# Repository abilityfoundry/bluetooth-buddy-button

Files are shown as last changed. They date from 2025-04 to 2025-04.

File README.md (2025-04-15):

# 🟢 Buddy Button

**Open-Source Accessibility. One Click at a Time.**

The Buddy Button is an open-source Bluetooth-enabled switch designed for accessibility. Built to be 3D printed and easily assembled, this device enables users with limited mobility to interact with computers, tablets, or phones using a single press.

Created by [**Ability Foundry**](https://github.com/abilityfoundry), this project is part of our mission to build inclusive, impactful, and low-cost assistive technology tools for everyday use.

---

## 📸 3D Renders

Visual previews of the Buddy Button housing and how it fits together:

| Bottom View | Top View | Assembly View |
|---|---|---|
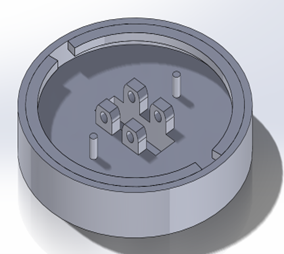
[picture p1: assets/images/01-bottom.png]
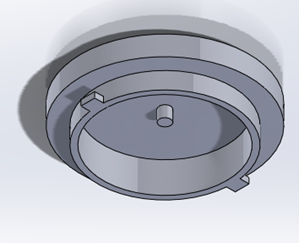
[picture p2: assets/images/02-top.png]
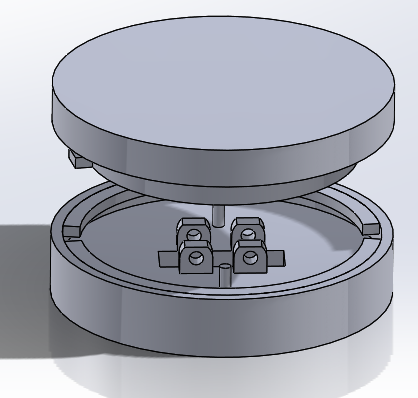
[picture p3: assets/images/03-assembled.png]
|  |  |  |

- **Bottom View**: Shows the internal mounting features for components.
- **Top View**: Displays the enclosure’s inner surface and guiding features.
- **Assembly View**: Illustrates how the top and bottom parts align during assembly.

---

## 🎯 What It Does

- 🖱️ Sends **wireless Bluetooth HID signals** (like keypresses)  
- 🔋 Runs on a **rechargeable LiPo battery**  
- 🌈 Uses a **NeoPixel RGB LED** for visual status  
- 🧩 Built to be **modular and customizable** (shape, color, sensitivity)  
- 🛠️ Easy to assemble using **3D-printed parts** and off-the-shelf components  

---

## 🧱 What's in This Repo

- `Buddy Button Instructions.md` – Complete build instructions  
- `/assets/buddy_button.ino` – Arduino code  
- `/assets/STLs/` – 3D-printable STL files  
- `/assets/SLDPRTs/` – Editable SolidWorks CAD files  

---

## 🛠️ Requirements

- Adafruit Feather nRF52 Bluefruit LE  
- 150–500mAh LiPo Battery  
- RGB NeoPixel  
- Spring (McMaster #9657K289)  
- Momentary switch  
- Basic soldering + 3D printer  

Full list with prices and links is in the [Hardware Components](https://github.com/abilityfoundry/bluetooth-buddy-button/blob/main/Buddy-Button-Instructions.md) section of the instructions.

---

## 🚀 Get Started

1. Print the button housing from the STL files  
2. Order components (linked in the guide)  
3. Flash the Arduino code to the Feather  
4. Assemble, pair via Bluetooth, and press to interact

---

## 🤝 Contribute

Have ideas for improving the design? Want to help make assistive tech more accessible and affordable? We welcome contributions! Open an issue or submit a pull request.

---

**Ability Foundry**  
> Building technology for a more inclusive future.  
> https://github.com/abilityfoundry

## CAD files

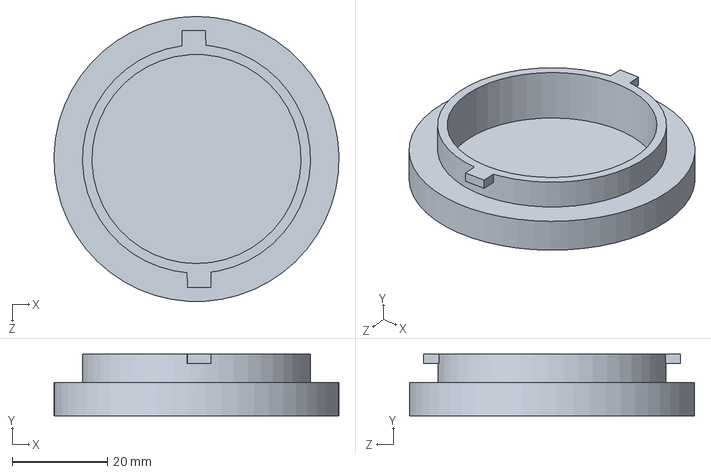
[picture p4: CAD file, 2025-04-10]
assets/SLDPRTs/bb-top.SLDPRT
60.0 x 13.0 x 60.0 mm

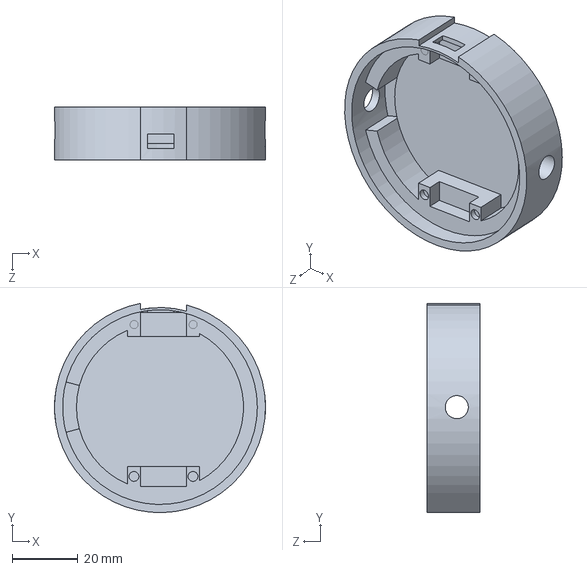
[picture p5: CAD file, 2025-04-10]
assets/SLDPRTs/bb-base.SLDPRT
64.0 x 63.4 x 16.0 mm

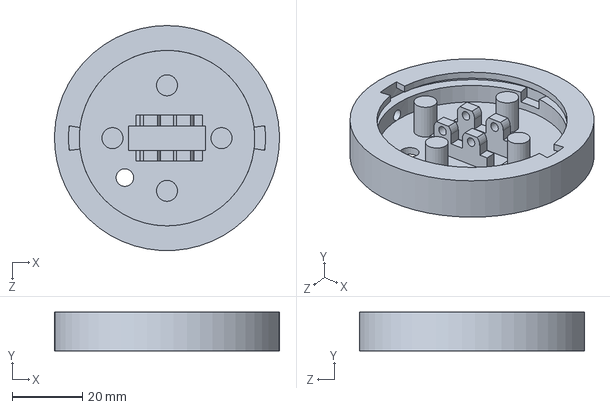
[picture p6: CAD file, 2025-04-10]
assets/SLDPRTs/bb-bottom.SLDPRT
64.0 x 11.0 x 63.9 mm

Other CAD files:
assets/STLs/bb-base.stl
assets/STLs/bb-bottom.stl
assets/STLs/bb-top.stl

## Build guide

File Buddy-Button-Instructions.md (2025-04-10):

# Ability Foundry Bluetooth Buddy Button Project

## Included Files
This repository contains everything you need to build your own Buddy Button:

- `/Buddy Button Instructions.md` — You are reading it now.
- `/assets/buddy_button.ino` — Arduino sketch for controlling the button’s behavior
- `/assets/SLDPRTs/` — SolidWorks files for the top, bottom, and base components (`bb-top.SLDPRT`, `bb-bottom.SLDPRT`, `bb-base.SLDPRT`)
- `/assets/STLs/` — Exported STL versions for easy 3D printing
- `/Parts List.txt` — Links and descriptions for all recommended components

## Table of Contents
- [Overview](#overview)
- [Hardware Components](#hardware-components)
- [Mechanical Design](#mechanical-design)
- [Electronics Setup](#electronics-setup)
- [Code Explanation](#code-explanation)
- [How to Upload the Code](#how-to-upload-the-code)
- [Usage](#usage)
- [Future Improvements](#future-improvements)
- [References](#references)

---

## Overview
The **Buddy Button** is a customizable, accessible Bluetooth-enabled button designed for users with motor disabilities or for use in maker projects. It combines a tactile, 3D-printed enclosure with internal electronics capable of sending **wireless HID signals** (like keypresses) to a phone, tablet, or computer. Key features include:

- A **mechanical spring-loaded design** that gives responsive feedback.
- A **NeoPixel RGB LED** that indicates status (e.g., charging, pairing, low battery).
- **Bluetooth HID support** using the Adafruit Feather nRF52 Bluefruit LE, allowing the button to act like a wireless keyboard or mouse.
- **Rechargeable power** using a small **LiPo battery** (150–500mAh).
- **Modular customization** options such as different button tops, textures, and spring sensitivities.

### Example Use Cases
- Assistive tech for users needing a larger or more responsive external button.
- DIY projects where Bluetooth control is needed via a tactile input.
- Classroom demos for HID/Bluetooth hardware projects.

### Key Parts Used
- [**Adafruit Feather nRF52 Bluefruit LE**](https://www.adafruit.com/product/3406) — BLE microcontroller with HID support  
- [**LiPo Batteries - 150mAh**](http://www.adafruit.com/product/1317) and [500mAh**](https://www.adafruit.com/product/1578) — rechargeable power sources  
- [**RGB Smart LED (NeoPixel)**](https://www.adafruit.com/product/1260) — status indication  
- [**Spring (McMaster #9657K289)**](https://www.mcmaster.com/9657k289) — provides resistance and travel in button press  
- [**Feather Header Kit**](http://www.adafruit.com/product/2886) and [**Stacking Headers**](http://www.adafruit.com/product/2830) — to mount components cleanly inside the case

This modular design allows for experimentation and refinement across mechanical and electronic domains. The current iteration is Version 5, which uses a twist-to-lock mechanism and a fully embedded rechargeable system .

---

## Hardware Components
| Item | Description | Qty | Cost |
|---|---|-----|---|
| [Adafruit Feather nRF52 Bluefruit LE](https://www.adafruit.com/product/3406) | BLE HID microcontroller | 1 | $24.95 |
| [Feather Header Kit](http://www.adafruit.com/product/2886) | 12-pin and 16-pin male headers | 1 | $0.95 |
| [Feather Stacking Headers](http://www.adafruit.com/product/2830) | Female headers for stacking | 1 | $1.25 |
| [LiPo Battery - 3.7v 150mAh](http://www.adafruit.com/product/1317) | Rechargeable battery | 1 | $5.95 |
| [LiPo Battery - 3.7v 500mAh](https://www.adafruit.com/product/1578) | Alternative for longer runtime | 1 | $7.95 |
| [RGB Smart LED](https://www.adafruit.com/product/1260) | Status indicator light | 1 | $6.50 |
| [Spring (McMaster #9657K289)](https://www.mcmaster.com/9657k289) | Tactile feedback mechanism | 1 | $1.00 |
| 3D Printed Housing | Top and bottom shell | 1 | ~$2.00 (varies) |

Total estimated cost per unit: **$48.55**

---

## Mechanical Design

The mechanical design consists of:

- **Top Half**: Moves vertically when pressed. Contains a groove and locking tabs to allow travel and retention.
- **Bottom Half**: Holds the electronics and spring. Designed with cutouts for lock tabs and spring supports.

STL files for 3D printing are located in `/assets/STLs`. Original SolidWorks files are in `/assets/SLDPRTs`.

### Design Iterations
- **Version 3**: Reduced wall thickness to 1.5mm, improved space economy.
- **Version 4**: Added a twist-lock mechanism; adjusted tolerances for tighter fits.
- **Version 5**: Refined locking system, added a track-based twist-to-lock system with 2mm travel.

Wall thickness and spring support dimensions were iteratively refined for structural integrity without excess bulk. Design feedback was gathered by testing spring rigidity and assembly friction (see design notes in `/Parts List.txt` and source files).

---

## Electronics Setup

1. **Microcontroller**: Adafruit Feather nRF52
2. **Power**: LiPo battery connected to JST port (built-in charging circuit used)
3. **LED**: NeoPixel on pin D6, powered by 3.3V and grounded
4. **Battery Monitoring**: Analog pin A7 reads battery voltage through a voltage divider
5. **Button Input**: Momentary switch connects to a digital input pin

---

## Code Explanation

**File**: `/assets/buddy_button.ino`

### Battery Voltage Reading
```cpp
#define VBAT_PIN          (A7)
#define VBAT_MV_PER_LSB   (0.73242188F)
#define VBAT_DIVIDER      (0.71275837F)
#define VBAT_DIVIDER_COMP (1.403F)
```
These constants allow the analog input to read and compute the real battery voltage.

### BLE HID Setup
```cpp
BLEUart bleuart;
BLEHidAdafruit blehid;
BLEDis bledis;
```
These initialize the HID services for the device to act like a Bluetooth keyboard/mouse.

### LED Setup
```cpp
Adafruit_NeoPixel strip = Adafruit_NeoPixel(60, PIN, NEO_GRB + NEO_KHZ800);
```
This sets up the NeoPixel strip (or single LED). Adjust number as needed.

### Loop Logic
In `loop()`, it checks BLE connections, reads the button state, updates LED colors, and triggers HID actions.

---

## How to Upload the Code

1. Install the **Arduino IDE**.
2. Add **Adafruit nRF52** boards via the Board Manager.
3. Install required libraries:
   - Adafruit Bluefruit nRF52
   - Adafruit NeoPixel
4. Connect the Feather to USB and select it under **Tools > Port**.
5. Open `/assets/buddy_button.ino` and click **Upload**.

---

## Usage

1. **Power On**: Plug in a LiPo battery or USB.
2. **Bluetooth Pairing**: Look for `Bluefruit52` on your phone/tablet/computer and pair.
3. **HID Activation**: Press the button to send key presses or other actions (customize in code).
4. **LED Status**: NeoPixel changes color based on charge/pairing/state.

---

## Future Improvements

- Slimmer housing with even smaller battery
- Software configuration to change actions
- Stronger or softer springs depending on user feedback
- Optional wired version for simpler setups
- Improved app integration for iOS/Android

---

## References

- [Adafruit Feather nRF52 Guide](https://learn.adafruit.com/bluefruit-nrf52-feather-learning-guide/downloads)
- [NeoPixel LED Downloads](https://learn.adafruit.com/flora-rgb-smart-pixels/downloads)

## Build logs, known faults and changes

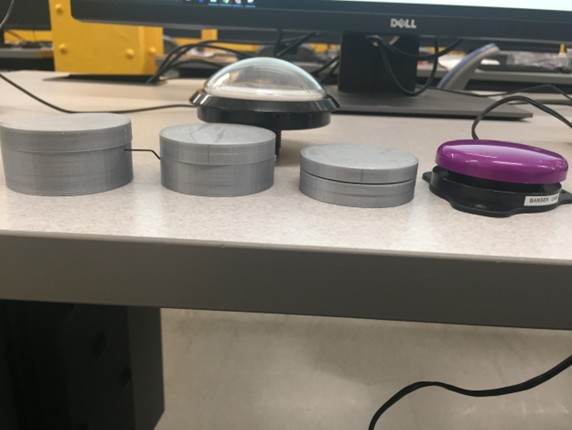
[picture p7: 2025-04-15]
assets/images/version-history.jpg

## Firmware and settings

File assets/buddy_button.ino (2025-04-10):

#define VBAT_PIN          (A7)
#define VBAT_MV_PER_LSB   (0.73242188F)   // 3.0V ADC range and 12-bit ADC resolution = 3000mV/4096
#define VBAT_DIVIDER      (0.71275837F)   // 2M + 0.806M voltage divider on VBAT = (2M / (0.806M + 2M))
#define VBAT_DIVIDER_COMP (1.403F)        // Compensation factor for the VBAT divider

// HID bluetooth
#include <bluefruit.h>

#include <Adafruit_NeoPixel.h>
#ifdef __AVR__
  #include <avr/power.h>
#endif
// Function prototypes for packetparser.cpp
uint8_t readPacket (BLEUart *ble_uart, uint16_t timeout);
float   parsefloat (uint8_t *buffer);
void    printHex   (const uint8_t * data, const uint32_t numBytes);

// Packet buffer
extern uint8_t packetbuffer[];

BLEUart bleuart;
BLEDis bledis;
BLEHidAdafruit blehid;
//Color LED


#define PIN 6

Adafruit_NeoPixel strip = Adafruit_NeoPixel(60, PIN, NEO_GRB + NEO_KHZ800);





bool hasKeyPressed = false;


int readVBAT(void) {
  int raw;

  // Set the analog reference to 3.0V (default = 3.6V)
  analogReference(AR_INTERNAL_3_0);

  // Set the resolution to 12-bit (0..4095)
  analogReadResolution(12); // Can be 8, 10, 12 or 14

  // Let the ADC settle
  delay(1);

  // Get the raw 12-bit, 0..3000mV ADC value
  raw = analogRead(VBAT_PIN);

  // Set the ADC back to the default settings
  analogReference(AR_DEFAULT);
  analogReadResolution(10);

  return raw;
}

uint8_t mvToPercent(float mvolts) {
    uint8_t battery_level;

    if (mvolts >= 3000)
    {
        battery_level = 100;
    }
    else if (mvolts > 2900)
    {
        battery_level = 100 - ((3000 - mvolts) * 58) / 100;
    }
    else if (mvolts > 2740)
    {
        battery_level = 42 - ((2900 - mvolts) * 24) / 160;
    }
    else if (mvolts > 2440)
    {
        battery_level = 18 - ((2740 - mvolts) * 12) / 300;
    }
    else if (mvolts > 2100)
    {
        battery_level = 6 - ((2440 - mvolts) * 6) / 340;
    }
    else
    {
        battery_level = 0;
    }

    return battery_level;
}

void setup() {

  // Get a single ADC sample and throw it away
  readVBAT();

  //HID part

    Bluefruit.begin();
  // Set max power. Accepted values are: -40, -30, -20, -16, -12, -8, -4, 0, 4
  Bluefruit.setTxPower(4);
  Bluefruit.setName("Bluefruit52");


  // Configure and Start Device Information Service
  bledis.setManufacturer("Adafruit Industries");
  bledis.setModel("Bluefruit Feather 52");
  bledis.begin();

  /* Start BLE HID
   * Note: Apple requires BLE device must have min connection interval >= 20m
   * ( The smaller the connection interval the faster we could send data).
   * However for HID and MIDI device, Apple could accept min connection interval 
   * up to 11.25 ms. Therefore BLEHidAdafruit::begin() will try to set the min and max
   * connection interval to 11.25  ms and 15 ms respectively for best performance.
   */
  blehid.begin();

  // digital Pin defining
  pinMode(A3,INPUT);

  /* Set connection interval (min, max) to your perferred value.
   * Note: It is already set by BLEHidAdafruit::begin() to 11.25ms - 15ms
   * min = 9*1.25=11.25 ms, max = 12*1.25= 15 ms 
   */
  /* Bluefruit.setConnInterval(9, 12); */

  // Set up and start advertising
  startAdv();
 
}


void startAdv(void)
{  
  // Advertising packet
  Bluefruit.Advertising.addFlags(BLE_GAP_ADV_FLAGS_LE_ONLY_GENERAL_DISC_MODE);
  Bluefruit.Advertising.addTxPower();
  Bluefruit.Advertising.addAppearance(BLE_APPEARANCE_HID_KEYBOARD);
  
  // Include BLE HID service
  Bluefruit.Advertising.addService(blehid);

  // There is enough room for the dev name in the advertising packet
  Bluefruit.Advertising.addName();
  
  /* Start Advertising
   * - Enable auto advertising if disconnected
   * - Interval:  fast mode = 20 ms, slow mode = 152.5 ms
   * - Timeout for fast mode is 30 seconds
   * - Start(timeout) with timeout = 0 will advertise forever (until connected)
   * 
   * For recommended advertising interval
   * https://developer.apple.com/library/content/qa/qa1931/_index.html   
   */
  Bluefruit.Advertising.restartOnDisconnect(true);
  Bluefruit.Advertising.setInterval(32, 244);    // in unit of 0.625 ms
  Bluefruit.Advertising.setFastTimeout(30);      // number of seconds in fast mode
  Bluefruit.Advertising.start(0);                // 0 = Don't stop advertising after n seconds
  
}
void loop() {
  hasKeyPressed=false;
 // HID part
   // Only send KeyRelease if previously pressed to avoid sending
  // multiple keyRelease reports (that consume memory and bandwidth)
  if ( hasKeyPressed )
  {
    hasKeyPressed = false;
    blehid.keyRelease();
    
    // Delay a bit after a report
    delay(5);
  }
    
  

  char a= ' ';
  int b=digitalRead(A3);
  
  if(b>0){ 
  hasKeyPressed = true;
    blehid.keyPress(a);  
  }
    blehid.keyRelease();

  // Request CPU to enter low-power mode until an event/interrupt occurs
  waitForEvent(); 
  
//Low battery part
  
  // Get a raw ADC reading
  int vbat_raw = readVBAT();

  // Convert from raw mv to percentage (based on LIPO chemistry)
  uint8_t vbat_per = mvToPercent(vbat_raw * VBAT_MV_PER_LSB);

  // Convert the raw value to compensated mv, taking the resistor-
  // divider into account (providing the actual LIPO voltage)
  // ADC range is 0..3000mV and resolution is 12-bit (0..4095),
  // VBAT voltage divider is 2M + 0.806M, which needs to be added back
  float vbat_mv = (float)vbat_raw * VBAT_MV_PER_LSB * VBAT_DIVIDER_COMP;
     
  //LED color change to show  low battery
  if(vbat_per<40){
  colorWipe(strip.Color(255,0,0), 1000);
}
else{
   colorWipe(strip.Color(0,0,0), 1000);
}
}

void rtos_idle_callback(void)
{
  // Don't call any other FreeRTOS blocking API()
  // Perform background task(s) here
}


void colorWipe(uint64_t c, uint8_t wait) {
  for(uint16_t i=0; i<strip.numPixels(); i++) {
    strip.setPixelColor(i, c);
    strip.show();
  }
}
